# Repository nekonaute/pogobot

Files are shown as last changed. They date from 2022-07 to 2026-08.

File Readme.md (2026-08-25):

# Pogobot

## Overview 
The pogobot is a small robot designed for swarm robotics experiments, targeted at collective behaviour and social learning research.
The robot is composed of a head (above) with a iCE40UP5K FPGA chip including a softcore processor, an IMU, fast Infra-Red communication devices and a LED.
The head is plugged on a belly (under) which composed of even more LEDs, the motor controler, the battery and the battery regulation system.

## Git description
This project is divided into 5 folders :

- 3d-addons
- docs
- Hardware
- Software
- Scripts

3d-addons contains the 3d printable mesh necessary to assemble a complete robot. 

Hardware contains the schematics and other files to build your own robot from scratch. 

All the schematics were done using KiCad 6. You can find : 
- 'Belly' folder with the belly schematics
- 'Head' folder with the head schematics
- '3Dmodels' and other folders regroups all the libraries, 3D models and foorprints for KiCad.
   
Software contains the gateware / software / SDK builder in expert mode to upload inside the robot.
It exists 2 softwares inside the robot. 
- The bootloader is the one called when you boot the robot. It contains a gateware and the pogobios.
- The user space is called by a command inside the bootloader. It contains your code and a gateware. <br>
/!\ If you plan to use the pogobot in the user space please use the sdk [here](https://github.com/nekonaute/pogobot-sdk).
  
Scripts corresponds to the differents scripts used around the robot.

## Shortcuts to

- [Robot Assembly for Users](./docs/RobotAssembly.md)
- [Software documentation for Users](./docs/SoftwareUserGuide.md)
- [Software documentation for Experts](./Software/Readme.md)
- [Pogobot Remote Tool](./docs/IR-Remote.md)
- [Pogobot Charger Tool](./Hardware/Readme.md#charger)
- [Pogobot Wall Tool](./Hardware/Readme.md#ir-wall)
- [Pogobot Wall App](./Software/pogoWallApp/Readme.md)
- [Pogobject Tool](./Software/pogobject/Readme.md)
- [Hardware documentation](./Hardware/Readme.md)

# Pogobot Extended Universe

- [Pogobot Projet Entry Page](https://pogobot.github.io/)
- [SDK Repository](https://github.com/nekonaute/pogobot-sdk)
- [Pogobot2026 Tracking Software](https://github.com/keivan-amini/pogotrack)
- [Pogobot Simulator](https://github.com/Adacoma/pogosim)
- [Pogobot Software Addons](https://github.com/Adacoma/pogo-utils)

# Project History

To help the understanding, there is two version names used inside the project, one for the hardware and one for the software. <br> 
The following table gives an overview :

| hardware version | software version | comments |
|:---:|:---:|---|
| V3 | V1 | initial version |
| V3 | V2 | reduce communication speed to increase reliability |
| V3 | V2.1 | reduce header footprint |
| V3 | V2.2 | introduce short message and clean the pogobios |
| V3 | V2.2.1 | fix the IR programation problem |
| V3 | V2.3 | API standardization : motor |
| V3 | V2.4 | API standardization : IR messaging |

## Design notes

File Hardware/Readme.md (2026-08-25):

# Hardware
Here you can find the description and information for each part developped.

<!-- vscode-markdown-toc -->
- [Hardware](#hardware)
  - [Folder description](#folder-description)
  - [Pogobot robot](#pogobot-robot)
    - [Hardware schematic](#hardware-schematic)
    - [What's needed for 1 robot](#whats-needed-for-1-robot)
    - [Motor information](#motor-information)
    - [3d printed parts](#3d-printed-parts)
  - [USB UART progboard](#usb-uart-progboard)
  - [Charger](#charger)
  - [IR remote](#ir-remote)
  - [IR Wall](#ir-wall)
  - [Pogobject](#pogobject)

<!-- vscode-markdown-toc-config
	numbering=false
	autoSave=true
	/vscode-markdown-toc-config -->
<!-- /vscode-markdown-toc -->

## Folder description
In this folder, you can find 3d models and kicad files.

The folder :
- "3Dmodels" contains the 3D models for Kicad
- 'Belly" contains the kicad files for the belly
- "Charger" contains the kicad files for the charger
- "Footprints.pretty" is the Kicad library for custom footprints
- "Head" contains the kicad files for the head
- "pogo_object" contains the kicad files for the pogobject
- "remote" contains the kicad files for the board which host the head of a remote
- "remote_leds_strip" contains the kicad files for the "shower" part of a remote
- "remote_leds_wall_ctrl" contains the kicad files for the amplification signal for a led strip
- "remote_leds_wall_strip" contains the kicad files for the strip leds of a wall remote
- "Symbols" contains the custom symbols for kicad
- "usb-uart-progboard" contains the kicad files for the programmation board by cable

## Pogobot robot

### Hardware schematic
Here you can find the global view of the hardware.

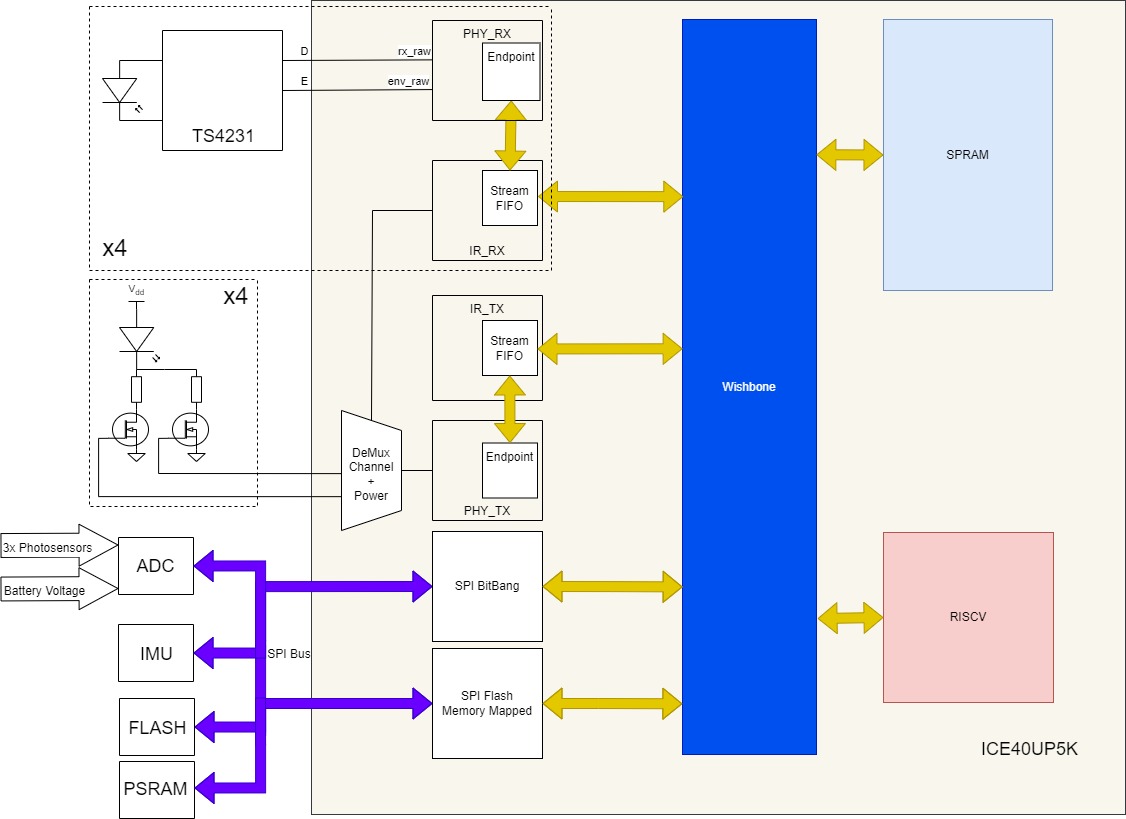
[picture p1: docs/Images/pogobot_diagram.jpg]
diagram


### What's needed for 1 robot

In order to complete a robot, you will need : 
- a belly and a head
- a 3v CR2 rechargeable Batery (Li-FePO4)
- 3 motors
- the different 3d printed parts

### Motor information
All the models are designed for the motors available here:
<!-- https://www.aliexpress.com/item/32918768766.html old ref -->
https://www.ebay.com/itm/115374108208

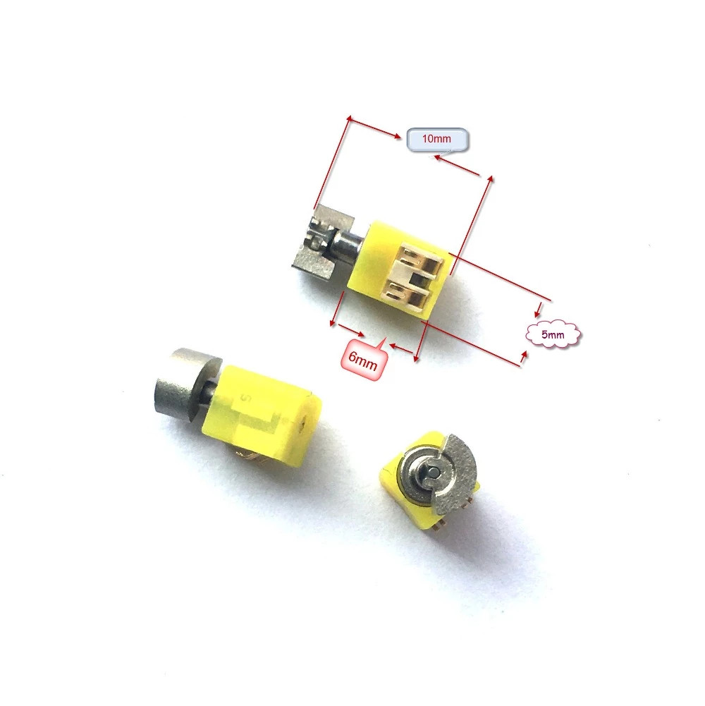
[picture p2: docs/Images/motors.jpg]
motor


### 3d printed parts
All the parts are available inside the folder '3d-addons', along with [assembly instructions](../3d-addons/Readme.md).

## USB UART progboard
In order to program the robot by cable, you need a USB to UART device connected between your computor and the FFC/FPC connector on the head. 
The folder 'Hardware/usb-uart-progboard' contains the Kicad files to produce a small board to program the robot. 
You also need :
- UMFT234XF board (https://www.mouser.fr/ProductDetail/FTDI/UMFT234XF?qs=NVftvxkm2thPJLzIkoAhbA%3D%3D)
- a FFC/FPC connector (8 pins, 0.5 mm, SMD/SMT, Right Angle, Dual Contact) like https://www.mouser.fr/ProductDetail/571-2328702-8
- a FFC/FPC cable (8 pins, 0.5 mm) like https://www.mouser.fr/ProductDetail/538-15166-0087
- a USB micro => USB cable

## Charger
There is two ways to recharge a pogobot:
- by the programming cable
- by the plus and minus pads on the head

In order to charge multiple robot at once, we develop a charger using pogopins that connect the plus and minus on the head of the robot by flipping the robot.

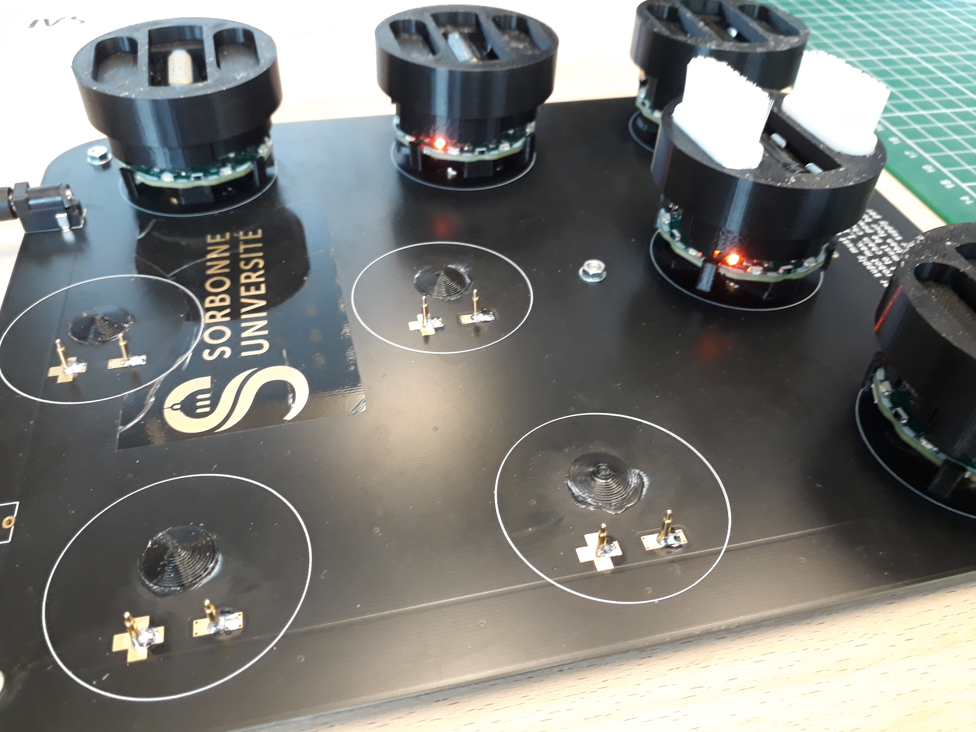
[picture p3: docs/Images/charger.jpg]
pogobot charger


The PCB cad files are available in the folder.
The pogopin used are these : https://www.digikey.fr/en/products/detail/preci-dip/90224-AS/5451911
We also used one power jack 5.1 embase connected to the power outlet. The second one is used, if you want to daisy chain multiple PCB (be careful, the total amps used).
:warning: The power plug has to expose the +5v on the inner contact and Ground on the outer contact. Please verify with a voltmeter before pluggin a robot.

We developed some small feet to mount with M3 screws on the PCB and some small cones in order to help the contacts for each robot.
Both 3d designs are available in the folder "3d-addons" (pogocharger*).

## IR remote
2 types of IR remote are possible. A small one and one with a shower. 

The small one is combination of a pogobot head + usb-uart-progboard + 3D structure (pogoremote_down.stl + pogoremote_up.stl) + 2 M3x10mm screws.

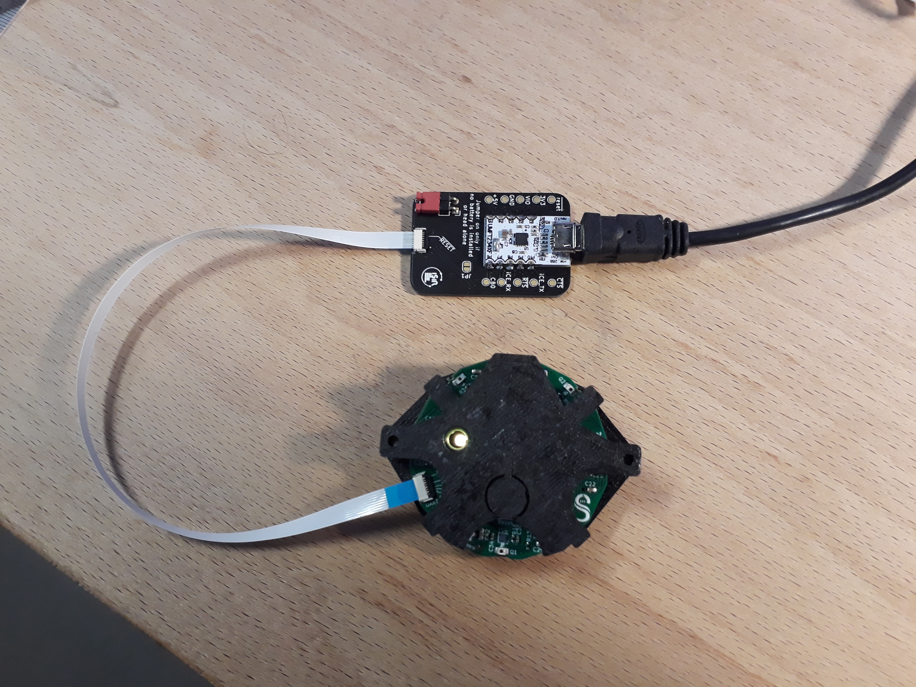
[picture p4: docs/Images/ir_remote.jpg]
IR_ Remote


The big one is combination of a pogobot head + remote + remote_Leds_strip + 3D structure

The leds are TSAL6200.

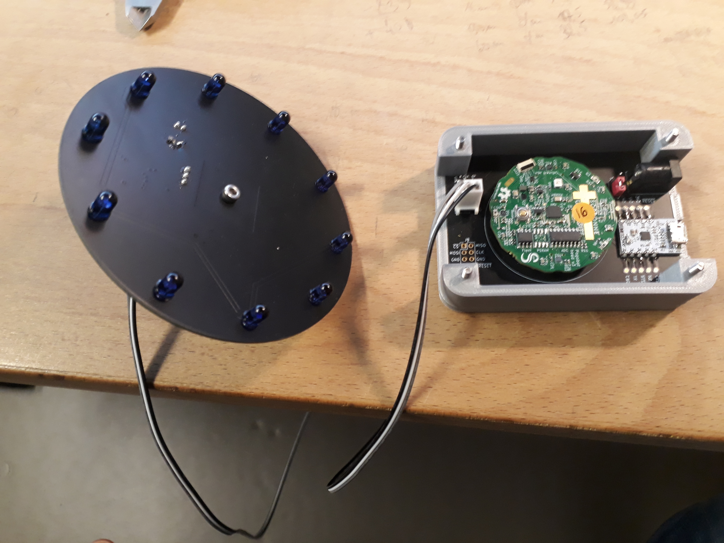
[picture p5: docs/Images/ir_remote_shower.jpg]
IR_ Remote


This version can use the USB alimentation or an external one (up to 12v) to extend the range of the remote. The jumper near the power jack determine the origin of the tension for the Leds.

## IR Wall 

The IR wall is a modified remote that can connect a long strip of Leds.
We didn't manage to find the correct Led strip for our application so we designed a strip led (remote_leds_wall_strip) that was produiced on flexible pcb. 

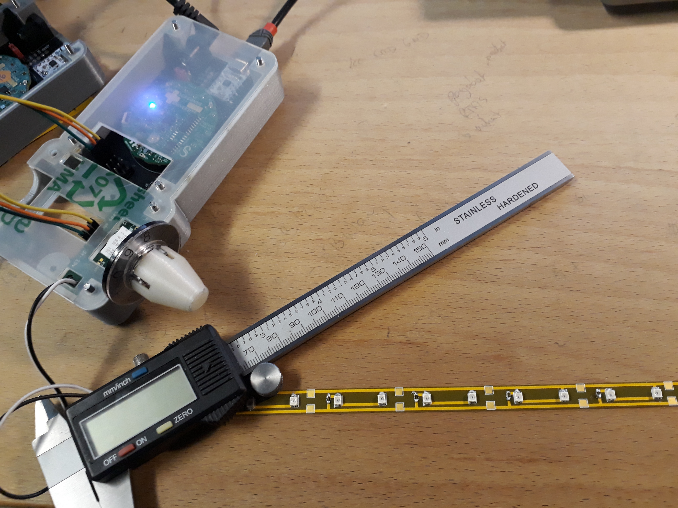
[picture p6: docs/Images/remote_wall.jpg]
IR_ Remote


To produice a IR wall, you need a pogobot head + remote + remote_leds_wall_ctrl + remote_leds_wall_strip. 

The leds are VSM3940x01.

## Pogobject

The pogobject is composed of a dfrobot firebeatle + pogobot head + pogo_object PCB. Through WIFI, it can be possible to send command to the pogobot head and so to change the message send by the object.

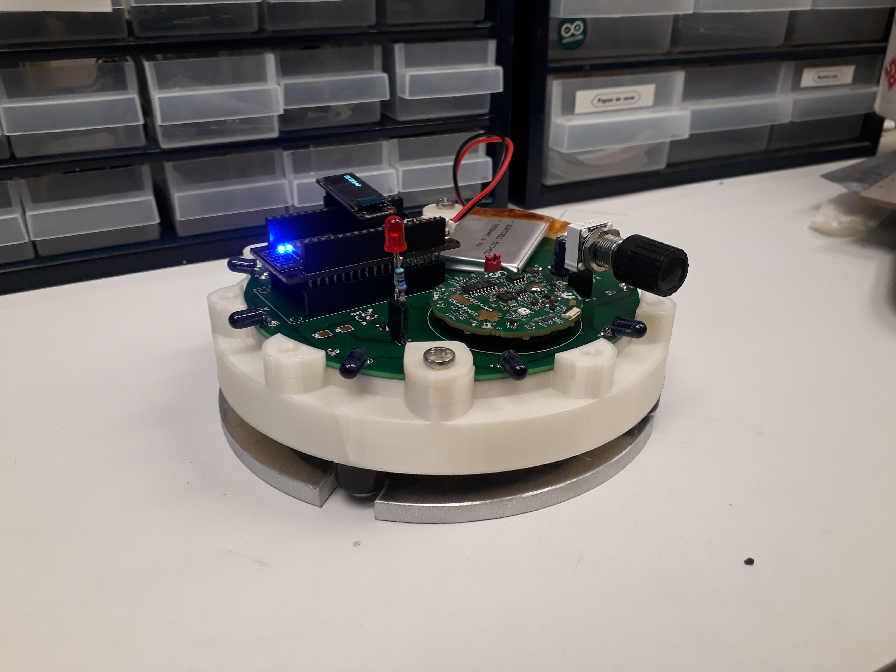
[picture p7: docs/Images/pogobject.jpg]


The pogobject is a large PCB that contains all the electronics. It is placed inside a 3d printed structure. This structure is placed on 4 caster with metal ball (pololu item 953) in order to be pushed by the robot. To make it fixed a aluminum weight is used to held it in place. 

The leds are TSAL6200.

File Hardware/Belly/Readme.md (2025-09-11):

# Belly
Belly board (Kicad project) to use with head board (pogobot v2).
Holds the battery, battery charger, motors, ...

## Belly v2
file : bellyv2

## Belly V3
file : pogobot_belly

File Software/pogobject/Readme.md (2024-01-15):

# Pogobject
The Pogobject is an object that can interact with pogobots using Infrared (IR) communication.
It features:
- IR message sending capability
- REST API control
- LEDs output control
- Battery-powered capability
- A screen

It is composed of a custom PCB, a Pogobot v3 head, and a DFRobot FireBeetle ESP8266.

## Pogobject configuration
In order to configure the SSID and the password of your WIFI, move the pogobject in configuration mode by connecting D9 to VCC and restart the pogobject.

A new WIFI "PogobjectConfig" should appear with the password "pogobotconfig".
Connect to the WIFI and go to the adress http://192.168.4.1 , enter the information.
Reconnect D9 to GND and restart the pogobject. 

You should now be connected to your network.

## Pogobject Directory
This directory contains the code for the FireBeetle to be used with the Arduino IDE.
Instructions and library versions are available within the code.

Tested with the arduino IDE 1.8.13 and 2.2.1
this code is the fusion of example from the libraries
- aREST (https://github.com/marcoschwartz/aREST v2.9.7)
- SoftwareSerial
- dfRobot u8g2 (https://github.com/olikraus/u8g2 v2.27.2 or v2.34.22)
- board library FireBeetle-ESP8266 (https://raw.githubusercontent.com/DFRobot/FireBeetle-ESP8266/master/package_firebeetle8266_index.json or http://download.dfrobot.top/boards/package_DFRobot_index.json v2.3.3)

## Pogobject Web Control Directory
This directory contains a web app that can interact more easily with the Pogobject.
Both the Pogobject and the web app need to be on the same wifi network in order to work.
Instructions are provided on the web page.

## Pogobject API

The following API is available on the pogobject.

- Allows to access to the pogobject status. <br> 
http://X.X.X.X/

- Allows to send a cmd to the pogobot though the UART prompt. <br> 
http://X.X.X.X/cmd?params=YYY  <br> 
YYY -> all bios cmd compabible with the pogobot (without "", spaces are understand).<br> 
Example: http://X.X.X.X/cmd?params=autotest led
 
- Allows to change the PWM ratio of the pin "LED_PIN". <br> 
http://X.X.X.X/led?params=Y <br> 
Y -> [0:1024] <br>
Example: http://X.X.X.X/led?params=256
 
- Alows to reboot the pogobot for whatever is needed. <br>
http://X.X.X.X/reboot_p 

- update the battery reading. <br> 
http://X.X.X.X/read_bat

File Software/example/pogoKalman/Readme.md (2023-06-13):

# [Projet P-ANDROIDE - M1/S2 - 2023 - Partie calibration et filtre de Kalman](http://androide.lip6.fr/?q=node/674)

## Pogobot Calibration 

Functions used to calibrate the Pogobot: find the correct motor values (between 0 and 1023) which make the robot move forward without turning. Keep in mind that Pogobots are very sensitive to environmental perturbations. Dust, an uneven ground and older toothbrushes can affect the trajectory of a robot.<br />
To calibrate the robot, we turn on the motor for a short time, check if the robot turned left or right, ajust the values of the motors accordingly and repeat a few times.

**Functions:**

```C
void pogobot_quick_calibrate(int power, int* leftMotorVal, int* rightMotorVal);
```
>Call this function to calibrate the motors of the Pogobot at roughly ***power***. The value of ***power*** has to be between 0 and 1023. However, the lower the value, the less precise the calibration will be. Keeping ***power*** between 524 and 716 is a good idea.<br />
>The values are returned as integers through ***leftMotorVal*** and ***rightMotorVal***.

```C
void pogobot_calibrate(int power, int startup_duration, int try_duration, int number_of_tries, float correction, int* leftMotorVal, int* rightMotorVal);
```
>Same function as before, but gives more control to the user over its parameters.<br />
>Call this function to calibrate the motors of the Pogobot at roughly ***power***. During each try, the motors are turned on for ***startup_duration***ms before we actually collect IMU data. Then IMU data is collected during ***try_duration***ms. The experience is repeated ***number_of_tries*** times. Each time, robot_rotation****correction*** is applied to one of the motors. <br />
>In ***pogo_quick_calibrate()***, ***startup_duration*** = 500 ; ***try_duration*** = 750 ; ***number_of_tries*** = 15 and ***correction*** = 50.0f.<br />
>Be careful, if your pogobot is mounted backward, you might need to assign a negative value to ***correction***. 

## Kalman filter implementation in C

The Kalman filter is executable at runtime. It is used to reduce the noise from the IMU. In particular, the z axis of the gyroscope (horizontal rotation) can be used to determine if the pogobot is turning. It is used in pogobot_calibrate() but can be used elsewhere.

**Functions:**

```C
void extendedKalmanFilter(
    float z_k_observation_vector[][C],        // [1][6] 6x1
    float state_estimate_k_minus_1[][C],      // [1][6] 6x1
    float P_k_minus_1[][C],                   // [6][6] 6x6
    float A_k_minus_1[][C],                   // [6][6] 6x6
    float process_noise_v_k_minus_1[][C],     // [1][6] 6x1
    float Q_k[][C],                           // [6][6] 6x6
    float R_k[][C],                           // [6][6] 6x6
    float H_k[][C],                           // [6][6] 6x6
    float sensor_noise_w_k[][C],              // [1][6] 6x1
    // returns:
    float state_estimate_k[][C],              // [1][6] 6x1
    float P_k[][C]                            // [6][6] 6x6
    );
```
>Function to filter out noisy data (makes a prediction from the previous iteration then correct it with the new data). z_k_observation_vector should be the data read by the IMU : {acc[0], acc[1], acc[2], gyro[0], gyro[1], gyro[2]}. <br />
>The results are stored in state_estimate_k and P_k. At the next iteration, you should assign their values to P_k_minus_1 and state_estimate_k_minus_1. The other parameters don't need to be changed (initialize once then forget about them).

```C
void initExtendedKalmanFilter(
    int power,
    float state_estimate_k_minus_1[][C],      // [1][6] 6x1
    float P_k_minus_1[][C],                   // [6][6] 6x6
    float A_k_minus_1[][C],                   // [6][6] 6x6
    float process_noise_v_k_minus_1[][C],     // [1][6] 6x1
    float Q_k[][C],                           // [6][6] 6x6
    float R_k[][C],                           // [6][6] 6x6
    float H_k[][C],                           // [6][6] 6x6
    float sensor_noise_w_k[][C]               // [1][6] 6x1
    );
```
>Declare arrays and pass them as arguments of this function to initialize them, after which you can pass them as the corresponding parameters of extendedKalmanFilter().

## Debug, display and convenient functions

Useful functions, linked to the calibration of the pogobots or with a more general purpose.

**Functions:**

```C
void print_float(float i, int precision);
```
>Print a float to the console, because printf("%f", myFloat); doesn't work on pogobots. They're too cool for that.<br />
>Example: printf("one point two = "); print_float(1.22f, 10); printf("\n"); <br />
>Result: "one point two = 1.2\n"

```C
void print_kalman(int i, float state_estimate_k[][6], float acc[], float gyro[3]);
```
>Print to the console the IMU values with and without the Kalman filter. The parameter ***i*** is the current time in milliseconds.

```C
void pogobot_motor_jump_set(int power, int motor);
```
>Safely initiate motor value (short jumpstart if ***value*** is under 512).

```C
void combine_arrays(float res[], float arr1[], float arr2[], int len1, int len2);
```
>Combine arr1[len1] and arr2[len2] into res[len1+len2] (res = arr1 + arr2 in python)

```C
void split_array(float base[], float arr1[], float arr2[], int len1, int len2);
```
>Split base[len1+len2] into arr1[len1] and arr2[len2] by putting the len1 first elements into arr1 and len1+1 to len1+len2 into arr2

```C
void set_all_leds(int r, int g, int b);
```
>Set all of the pogobot's leds to the same color.

```C
void anim_same(void);
```
>Pretty animation.

```C
void anim_blink(int r, int g, int b, int number_of_blinks);
```
>All leds blinks ***number_of_blinks*** times. 

```C
void print_f_list(float* list, int len, int precision);
```
>Print an array of floats to the console with \t in between each element. There is no \n.

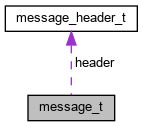
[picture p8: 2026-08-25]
Software/docs/doxygen/html/structmessage__t__coll__graph.png

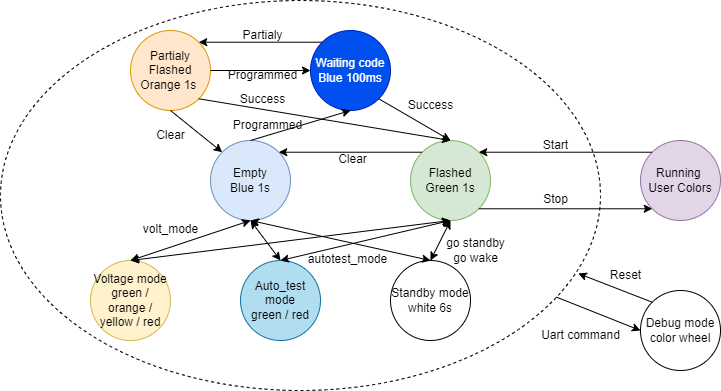
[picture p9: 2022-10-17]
docs/Images/pogobot_led_status.png

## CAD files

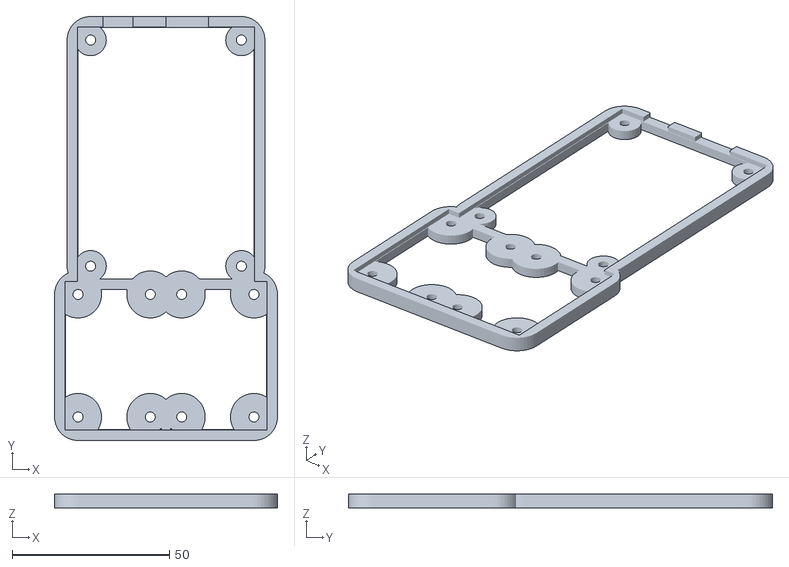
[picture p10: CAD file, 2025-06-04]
3d-addons/Misc/pogowall_ctrl_down.stl
71.0 x 135.0 x 4.60

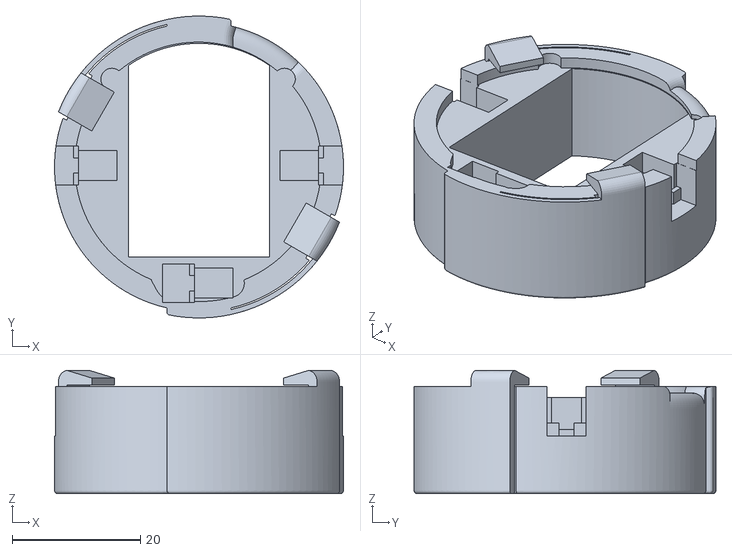
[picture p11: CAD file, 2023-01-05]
3d-addons/Pogobot2023/pogobot_bellyv3_cap.stl
45.0 x 47.0 x 19.2

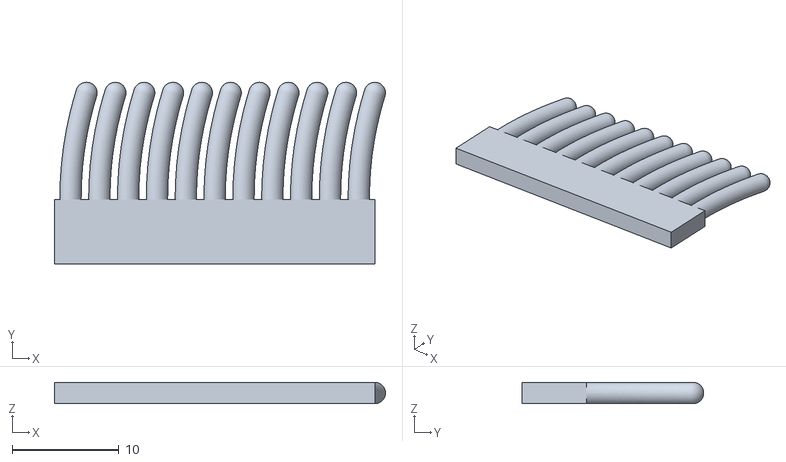
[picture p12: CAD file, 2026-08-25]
3d-addons/Pogobot2026/brushes.stl
31.0 x 17.0 x 2.00

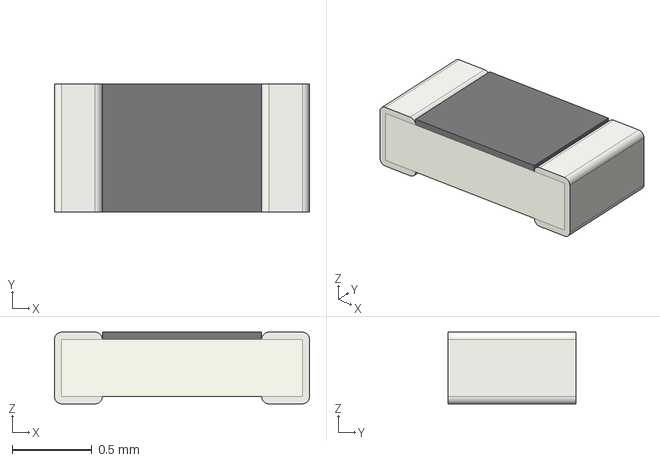
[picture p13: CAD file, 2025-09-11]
Hardware/3Dmodels/R_0603_1608Metric.step
1.60 x 0.8 x 0.45 mm

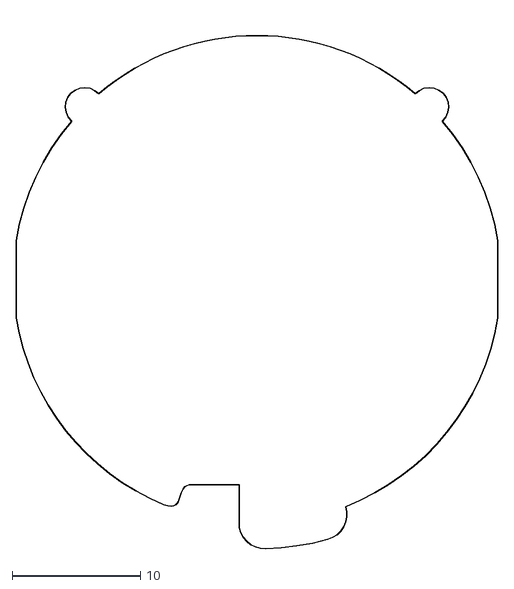
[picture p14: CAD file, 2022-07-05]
Hardware/Belly/untitled.dxf
37.5 x 41.5

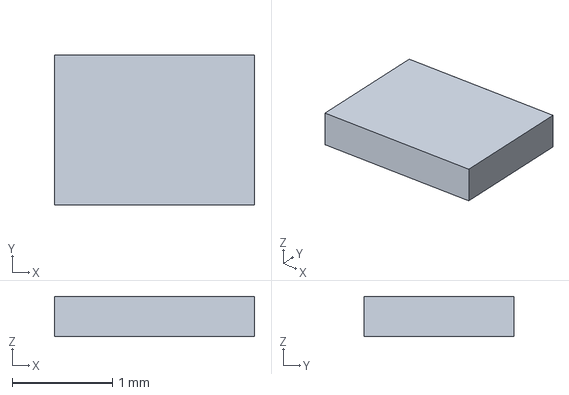
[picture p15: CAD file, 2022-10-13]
Hardware/remote_leds_wall_strip_12v/3Dmodels/TLA2024.step
2.00 x 1.50 x 0.4 mm

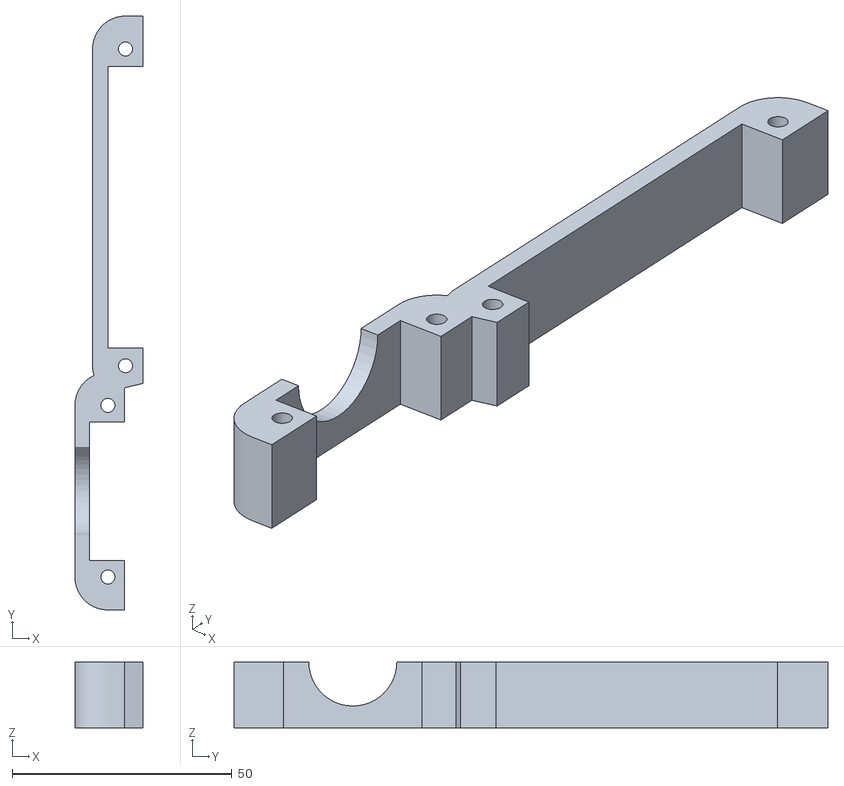
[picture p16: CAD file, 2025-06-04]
3d-addons/Misc/pogowall_ctrl_up_r.stl
15.5 x 135.0 x 15.0

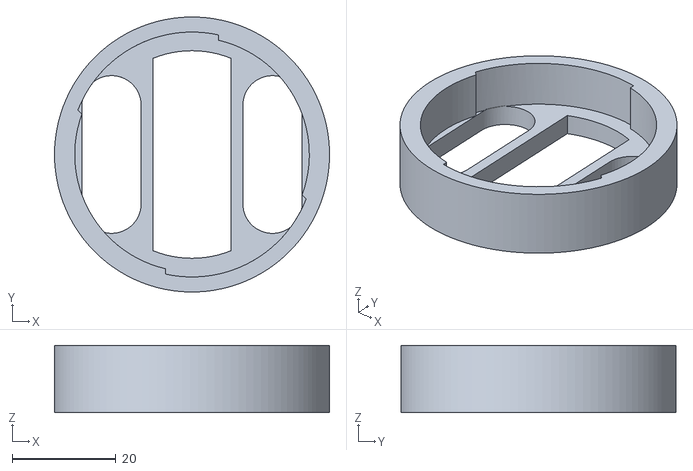
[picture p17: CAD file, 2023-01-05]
3d-addons/Pogobot2023/pogobot_bellyv3_skirt_brosse.stl
53.0 x 53.0 x 13.0

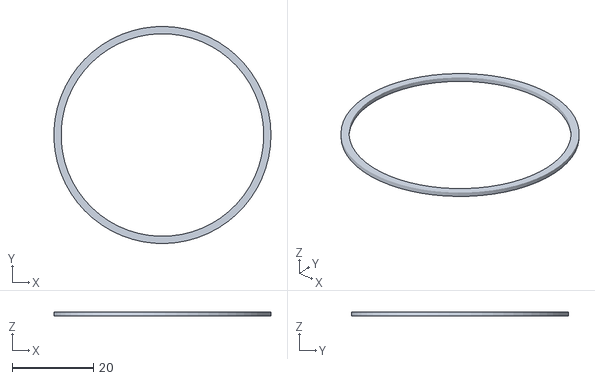
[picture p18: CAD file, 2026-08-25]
3d-addons/Pogobot2026/black_anulus.stl
53.4 x 53.4 x 1.00

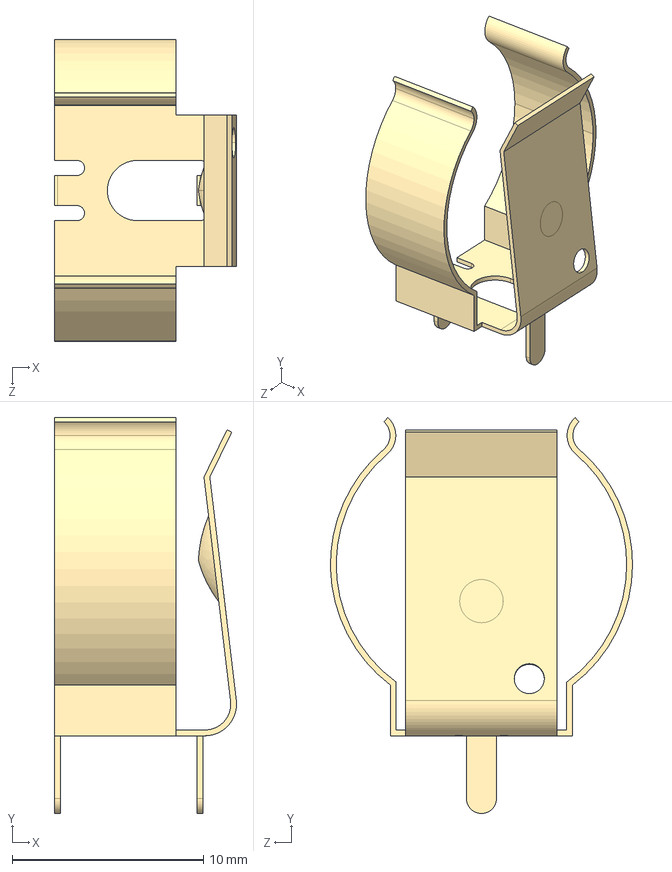
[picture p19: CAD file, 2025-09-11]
Hardware/3Dmodels/battery_clip.step
9.52 x 20.7 x 15.8 mm

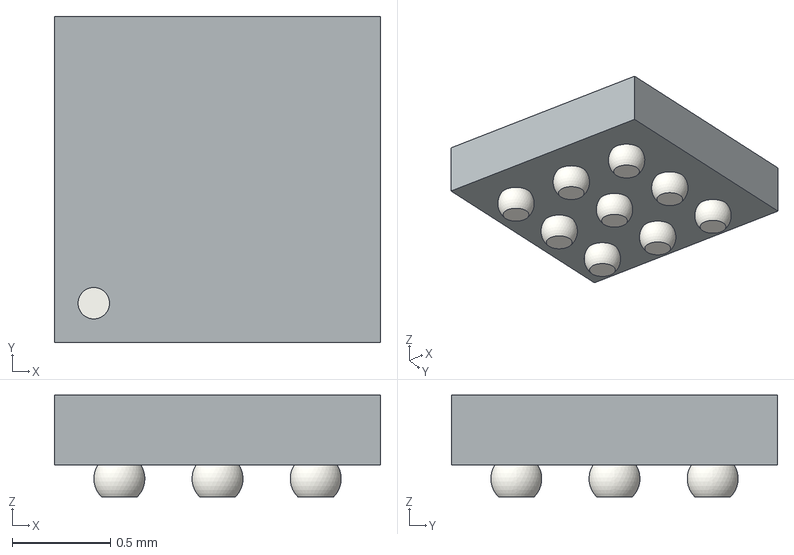
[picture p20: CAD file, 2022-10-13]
Hardware/remote_leds_wall_strip_12v/3Dmodels/TS4231.step
1.66 x 1.66 x 0.517 mm

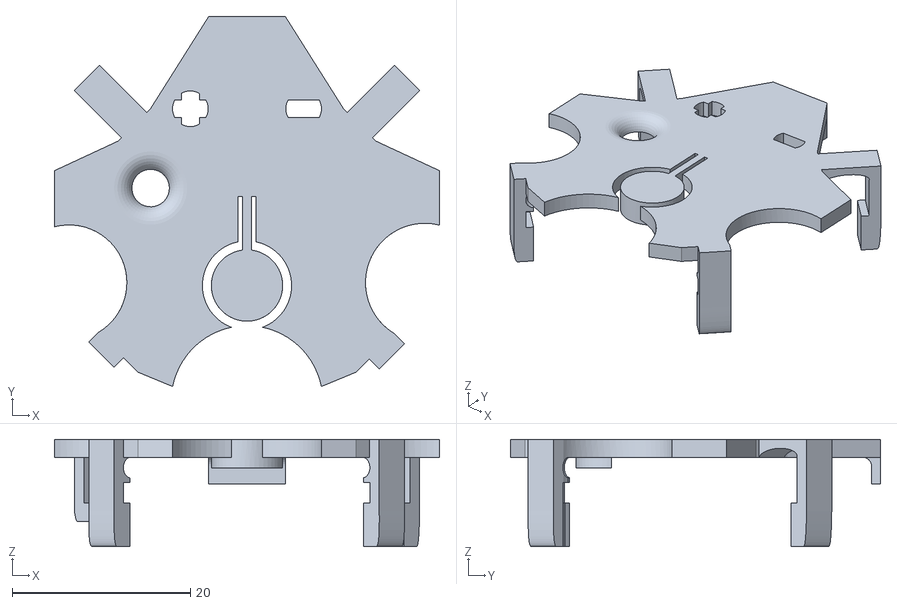
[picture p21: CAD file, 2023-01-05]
3d-addons/Pogobot2023/pogobot_headv3_hat.stl
43.2 x 41.5 x 12.0

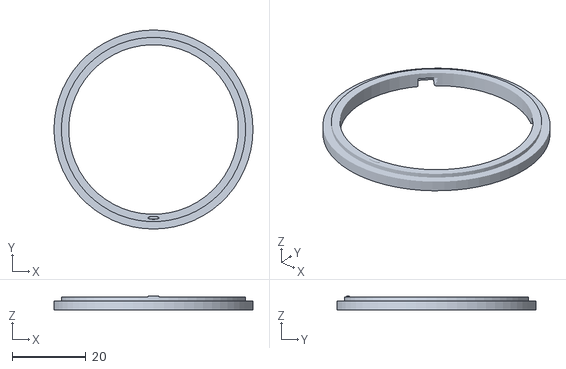
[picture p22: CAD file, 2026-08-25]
3d-addons/Pogobot2026/white_anulus.stl
53.9 x 53.9 x 3.84

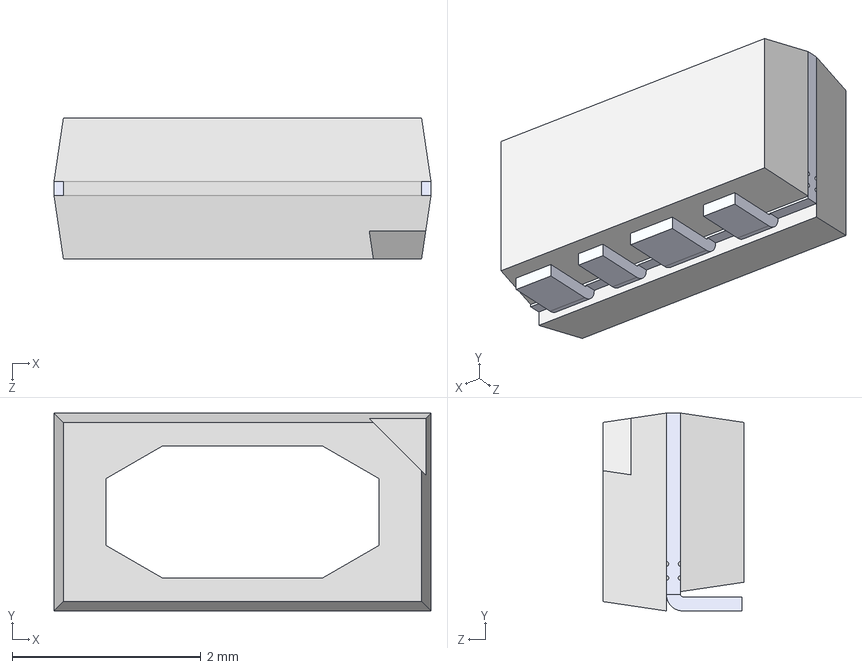
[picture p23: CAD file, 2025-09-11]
Hardware/3Dmodels/IN-PI42TASPRPGPB.step
4.00 x 2.10 x 1.50 mm

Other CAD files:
3d-addons/Misc/pogowall_ctrl_up_l.stl
Hardware/remote_leds_wall_strip_12v/3Dmodels/VEMD10940.step
3d-addons/Misc/pogoremote_up.stl
3d-addons/Pogobot2023/pogobot_bellyv3_skirt.stl
3d-addons/Misc/pogocharger_cone.stl
3d-addons/Misc/pogocharger_feet.stl
3d-addons/Misc/pogoremote_down.stl
3d-addons/Pogobot2026/black_capsule.stl
3d-addons/Pogobot2026/hat.stl
3d-addons/Pogobot2026/red_filters_back.stl
3d-addons/Pogobot2026/red_filters_front.stl
3d-addons/Pogobot2026/white_arrow.stl
Hardware/3Dmodels/10132797-015100LF.stp
Hardware/3Dmodels/10132797-035100LF.stp
Hardware/3Dmodels/C_0603_1608Metric.step
Hardware/3Dmodels/LED_0603_1608Metric.step
Hardware/3Dmodels/MCP73123-22SI_MF.stp
Hardware/3Dmodels/MSK12C02.stp
Hardware/3Dmodels/R_0805_2012Metric.step
Hardware/3Dmodels/WSON-8-1EP_2x2mm_P0.5mm_EP0.9x1.6mm.step
Hardware/remote_leds_wall_strip_12v/3Dmodels/2199119-3.stp
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

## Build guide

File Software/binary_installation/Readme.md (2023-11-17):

# How to use the compiled binaries

## Using the ice40 dev board

If you have access to the ice40 dev board and the complementary pogobot board as in the Readme section " Upload an empty or faulty robot ",
you can use the script "program_remote.sh" or "program_robot.sh" available for the version you need.

## Using Litex_term.py
### Installing the gateware and the pogobios

From the folder "pogobot/Software":

```
cp binary_installation/example_images.json .
```

Modify the path depending on the version needed and execute (replace XXX to match your configuration):

```
./litex_term.py --serial-boot --images example_images.json --safe /dev/ttyUSBXXX
```

Reboot the robot. It will then display the "pogoboot >" prompt

For the robot to download and restart with the new code, execute (on the robot):

```
serialboot
```

### Installing the remote gateware and pogobios

It is the same as the previous section but it uses the "example_images_remote.json" file instead.

/!\ The gateware of the remote and of a robot are different so the code of a robot can't run on a remote.

### In the case of the bootloader

In the folder "pogobot/Software" (replace XXX to match your configuration):

```
./litex_term.py --serial-boot --kernel=binary_installation/install_APIv2.2.1/bootloader/bootloader_pogobotv3/bootloader.bin --kernel-adr=0x200000 --safe /dev/ttyUSBXXX
```

On the robot, execute:

```
serialboot
```

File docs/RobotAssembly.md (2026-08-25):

# Robot Assembly
## Pogobot 2026

_not yet written_

## Pogobot 2023

### Printing info
The different models have been printed in PLA with an Ultimaker2+ with a layer height of 0.2mm without support or brim.

To assemble a robot, you need to print a skirt, a capsule and a hat for the version of your belly. <br>
After printed the capsule, you have to set free the tabs by gently cut under.

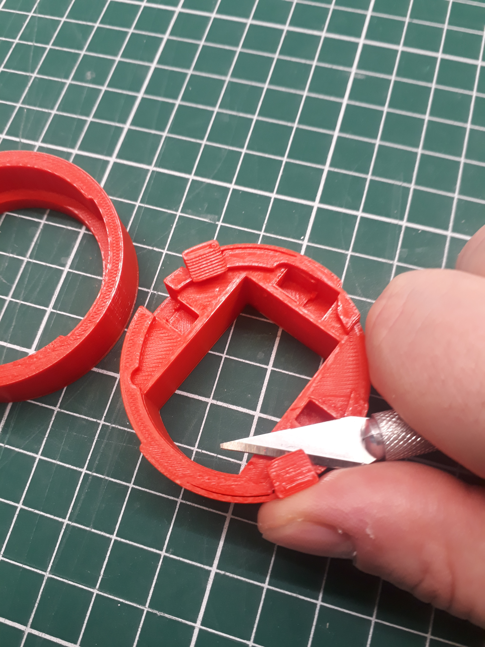
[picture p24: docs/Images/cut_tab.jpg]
cut_tab


HINT: The hat has to be returned to be printed without support.

### 3D parts Assembly
- First, place the motors inside the 3 holes.
- Then, place the robot inside the capsule.
- Finally, place the robot+capsule inside the skirt.

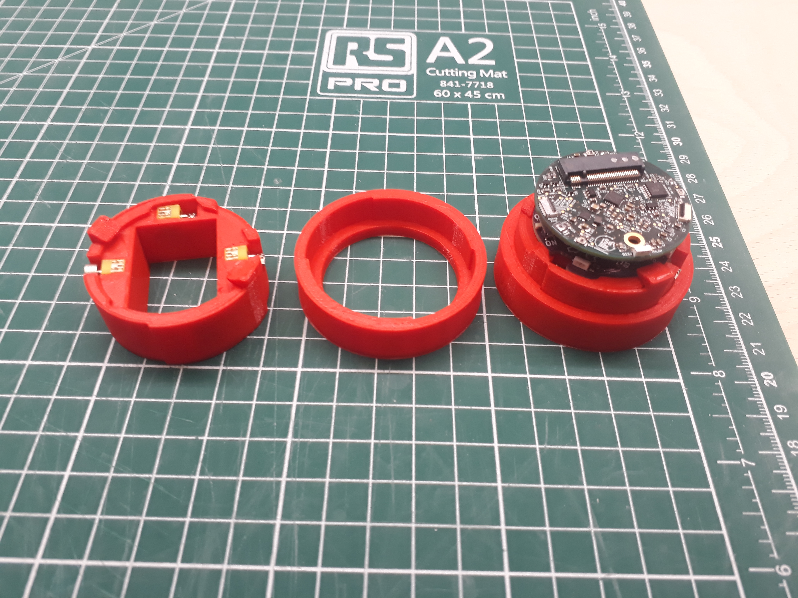
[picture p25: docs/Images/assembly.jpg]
assembly


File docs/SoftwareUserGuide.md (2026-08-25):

# Software Guide for Users

A practical introduction to programming a Pogobot for the first time. This document has been generated using human written parts and assembled with ChatGPT.

---

# 1. Introduction and Setup

## How are pogobot programmed ?

A Pogobot has programs written in **C** and uploaded either:

* through a **USB cable** (single robot),
* or through a **remote infrared uploader** (“shower” / walls) for multiple robots.

Typical Pogobot programs:

* blink LEDs,
* move motors,
* communicate through infrared messages,
* react to sensors,
* coordinate with other robots.

---

## Installing the Environment

You need the Pogobot SDK and toolchain installed before compiling programs. See [SDK repository and installation instructions](https://github.com/nekonaute/pogobot-sdk/tree/main#pogobot). As a reference point once the SDK is installed, you can navigate to the `helloworld` example under `pogobot-sdk/examples/helloworld`.

---

## Typical Program Structure

A Pogobot project usually contains:

```text
my_program/
├── main.c
└── Makefile
```

With the Makefile being essentially the same in every program, and as such can be copied from examples. Most programs follow this structure:

```c
#include "pogobot.h"

int main(void)
{
    pogobot_init();

    while (1)
    {
        // read sensors

        // communicate

        // move

        // blink LEDs

        msleep(10);
    }
}
```

---

# 2. First Program and Core SDK Concepts

## Minimal Example

### main.c

```c
#include "pogobot.h"

int main(void)
{
    pogobot_init();

    printf("init ok\n");

    while (1)
    {
        // Blue LED
        pogobot_led_setColor(0, 0, 255);

        // Move left motor
        pogobot_motor_set(motorL, motorFull);
        pogobot_motor_set(motorR, motorStop);

        msleep(500);

        printf("HELLO WORLD !!!\n");

        // Red LED
        pogobot_led_setColor(255, 0, 0);

        // Move right motor
        pogobot_motor_set(motorL, motorStop);
        pogobot_motor_set(motorR, motorFull);

        msleep(500);
    }
}
```

This program:

* initializes the robot,
* alternates LED colors,
* alternates motor movement,
* prints text to the serial terminal.

---

## Initialization

Every program must start with:

```c
pogobot_init();
```

Without initialization, most hardware features will not work.

---

## LEDs

Set the head LED color:

```c
pogobot_led_setColor(r, g, b);
```

Each value ranges from:

```text
0 → 255
```

Example:

```c
pogobot_led_setColor(255, 0, 0);
```

Red LED.

---

## Timing

Most programs use:

```c
msleep(milliseconds);
```

Example:

```c
msleep(500);
```

Waits 500 ms.

---

## Motors

Pogobot has 3 vibration motors:

```text
motorR
motorL
motorB
```

Motor power levels:

```text
motorStop          = 0
motorQuarter       = 256
motorHalf          ≈ 512
motorThreeQuarter  ≈ 716
motorFull          = 1023
```

Example:

```c
pogobot_motor_power_set(motorL, motorFull);
pogobot_motor_power_set(motorR, motorStop);
```

---

## Debug Printing

Use standard C printing:

```c
printf("Hello\n");
```

Messages appear in the serial terminal and are extremely useful for debugging.

---

## Sensors

### Ambient Light Sensors

```c
int value = pogobot_photosensors_read(0);
```

Sensors:

```text
0 = back
1 = front-left
2 = front-right
```

---

### Battery Voltage

```c
int mv = pogobot_battery_voltage_read();
```

Returns millivolts.

---

### IMU

```c
float acc[3];
float gyro[3];

pogobot_imu_read(acc, gyro);
```

Axes:

```text
0 = X
1 = Y
2 = Z
```

---

## Timers

### Stopwatch Example

```c
time_reference_t timer;

pogobot_stopwatch_reset(&timer);

// some computation

int32_t elapsed =
    pogobot_stopwatch_get_elapsed_microseconds(&timer);

printf("%ld\n", elapsed);
```

---

### Periodic Timer Example

```c
time_reference_t timer;

pogobot_timer_init(&timer, 1000000);

while (1)
{
    if (pogobot_timer_has_expired(&timer))
    {
        printf("1 second elapsed\n");

        pogobot_timer_offset_origin_microseconds(
            &timer,
            1000000
        );
    }
}
```

---

# 3. Infrared Communication and Swarm Programming

Pogobots communicate using infrared.

Typical workflow:

1. send a message,
2. periodically update IR system,
3. check if messages arrived,
4. read messages.

---

## Sending a Message

```c
char msg[] = "hello";

pogobot_infrared_sendShortMessage_omni(
    (uint8_t*)msg,
    sizeof(msg)
);
```

This broadcasts in all directions.

---

## Receiving Messages

```c
pogobot_infrared_update();

if (pogobot_infrared_message_available())
{
    message_t msg;

    pogobot_infrared_recover_next_message(&msg);

    printf("Message received\n");
}
```

---

## Example: Distributed Genetic Algorithm

The following program demonstrates:

* infrared swarm communication,
* distributed decision-making,
* mutation and selection,
* LEDs,
* motors,
* random genome generation.

Each robot:

1. generates a random binary genome,
2. computes a fitness score,
3. broadcasts its genome,
4. copies stronger genomes from neighbors,
5. occasionally mutates,
6. gradually converges toward an optimal genome.

This example comes from the distributed genetic algorithm demo in the SDK, `examples/demo_d2_9BIS`.

### Key Ideas

Genome representation:

```c
typedef struct my_data_t
{
    uint16_t genome;
    uint16_t fitness;
} my_data_t;
```

Broadcasting data:

```c
pogobot_infrared_sendLongMessage_omniGen(
    (uint8_t *)( &my_data ),
    sizeof( my_data )
);
```

Receiving and comparing genomes:

```c
if ( recept->fitness > my_data.fitness )
{
    my_data.genome = recept->genome;
}
```

Mutation:

```c
my_data->genome ^= 1UL << n;
```

This type of program is useful for experimenting with:

* swarm intelligence,
* collective optimization,
* decentralized coordination,
* emergent behavior.

---

# 4. Compiling, Uploading, and Running Programs

## Compiling

Inside your project folder:

```bash
make
```

If compilation succeeds, you should obtain:

```text
build/firmware.bin
build/firmware.elf
```

---

## Hardware Setup

For USB programming:

1. connect the robot to the programming board using the ribbon cable,
2. connect the programming board to your computer with USB.

When correctly powered, LEDs usually blink several colors during startup.

---

## Uploading Through USB

Connect to the robot:

```bash
make connect TTY=/dev/ttyUSB0
```

Replace:

```text
/dev/ttyUSB0
```

with the correct serial device on your machine.

---

## Terminal Workflow

After running `make connect`:

1. press ENTER,
2. wait for the prompt,
3. use terminal commands directly.

Upload firmware:

```text
serialboot
```

Run the uploaded program:

```text
run
```

Exit terminal:

```text
Ctrl+C Ctrl+C
```

---

## Uploading to Multiple Robots (Infrared Remote)

Connect the remote uploader:

```bash
make connect TTY=/dev/ttyUSB0
```

Then:

1. press ENTER,
2. type:

```text
run
```

3. power on robots,
4. erase firmware:

```text
rc_erase
```

5. flash robots:

```text
rc_flash_robot
```

6. start all robots:

```text
rc_start
```

Robots typically turn green when upload succeeds.

---

## Important Warning

Never use:

```text
serialboot
```

when connected to the infrared remote uploader.

Doing so overwrites the remote firmware itself.

---

# 5. Workflow, Troubleshooting, and Safety

## Recommended Development Workflow

A common workflow is:

1. modify `main.c`,
2. compile:

```bash
make
```

3. connect:

```bash
make connect
```

4. upload:

```text
serialboot
```

5. run:

```text
run
```

6. observe LEDs, movement, and debug prints,
7. repeat.

---

## Troubleshooting

### Robot Does Not Respond

Try:

* unplug/replug USB,
* restart terminal,
* power cycle robot,
* verify serial device path.

---

### Infrared Stops Working

Firmware 2.6 has a known IR bug.

Avoid resetting robots while they receive IR messages.

If IR breaks:

1. move robot away from others,
2. reset several times,
3. power cycle,
4. reflash firmware if needed.

---

### Program Too Large

Firmware 2.6 may fail when:

* `.data` exceeds about 41960 bytes,
* and the robot is started through `rc_start`.

Check size with:

```bash
riscv64-unknown-elf-size --format=SysV build/bin/firmware.elf
```

---

## Updating Robot Firmware

Firmware update instructions:

[Firmware update instructions](https://github.com/nekonaute/pogobot/blob/main/Software/Readme.md#upload-a-empty-or-faulty-robot)

Typical commands:

```bash
./program_robot.sh
```

or

```bash
./program_remote.sh
```

depending on the device.

---

## Safety Rules

* Power down robots before charging.
* Never leave robots charging unattended overnight.
* Do not leave robots on the arena after experiments.
* Fully charging takes about 2 hours.
* Avoid resetting robots during IR communication.

---

## Recommended Next Steps

After completing your first program:

1. explore the `examples/` folder,

2. experiment with:

   * swarm communication,
   * obstacle avoidance,
   * synchronization,
   * light-following behaviors,

3. create reusable helper functions,

4. test multi-robot behaviors with the infrared uploader.

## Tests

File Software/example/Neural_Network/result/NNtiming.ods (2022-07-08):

Pour 100 itérations
 | nb_inputs | nb_outputs | nb_hidden_layers | nb_hidden_nodes_per_layer | dimension | time x100 (s) | time (s) | Fréquence 1 itération
 | 20 | 10 | 3 | 30 | 2700 | 17,5 | 0,175 | 5,71428571428571
 | 20 | 10 | 4 | 30 | 3600 | 23,1 | 0,231 | 4,32900432900433
 | 40 | 20 | 6 | 40 | 10400 | 52 | 0,52 | 1,92307692307692
 | 10 | 5 | 3 | 15 | 675 | 6,3 | 0,063 | 15,8730158730159
 | 40 | 20 | 6 | 60 | 21600 | 84,7 | 0,847 | 1,18063754427391
 | 40 | 10 | 3 | 40 | 5200 | 27,2 | 0,272 | 3,67647058823529
 | 4 | 2 | 1 | 5 | 30 | 0,552 | 0,00552 | 181,159420289855
 | 4 | 2 | 2 | 5 | 55 | 0,952 | 0,00952 | 105,042016806723
 | 4 | 2 | 3 | 5 | 80 | 1,245 | 0,01245 | 80,3212851405622
 | 4 | 2 | 4 | 5 | 105 | 1,865 | 0,01865 | 53,6193029490617
 | 4 | 2 | 5 | 5 | 130 | 2,311 | 0,02311 | 43,271311120727
 | 4 | 2 | 6 | 5 | 155 | 2,78 | 0,0278 | 35,9712230215827
 | 4 | 2 | 7 | 5 | 180 | 3,214 | 0,03214 | 31,1138767890479
 | 4 | 2 | 8 | 5 | 205 | 3,642 | 0,03642 | 27,4574409665019
 | 4 | 2 | 9 | 5 | 230 | 4,201 | 0,04201 | 23,8038562247084
 | 4 | 2 | 10 | 5 | 255 | 4,545 | 0,04545 | 22,002200220022
 | 8 | 4 | 1 | 9 | 108 | 1,32 | 0,0132 | 75,7575757575758
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

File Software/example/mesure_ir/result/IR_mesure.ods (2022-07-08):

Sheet: monodirection
mesure pogobot
Angle 0°
vitesse Ko/s | size octet |  |  |  | 1ko => xus
distance cm | 32 | 64 | 128 | 256 |  | 32 | 64 | 128 | 256
0 | 8,47457627118644 | 15,3139356814701 | 25,6410256410256 | 38,6100386100386 | 0 | 118000 | 65300 | 39000 | 25900
0,5 | 8,47457627118644 | 15,3139356814701 | 25,6410256410256 | 38,6100386100386 | 0,5 | 118000 | 65300 | 39000 | 25900
1 | 8,47457627118644 | 15,3139356814701 | 25,6410256410256 | 38,6100386100386 | 1 | 118000 | 65300 | 39000 | 25900
1,5 | 8,47457627118644 | 15,3139356814701 | 25 | 38,6100386100386 | 1,5 | 118000 | 65300 | 40000 | 25900
2 | 5,20833333333333 | 8,62068965517241 | 8,08407437348424 | 6,12745098039216 | 2 | 192000 | 116000 | 123700 | 163200
2,5 | 0,302388872089507 | 0,666666666666667 | 1,39275766016713 |  | 2,5 | 3307000 | 1500000 | 718000
3 |  |  |  |  | 3
Angle +15°
vitesse Ko/s | size octet |  |  |  | 1ko => xus
distance cm | 32 | 64 | 128 | 256 |  | 32 | 64 | 128 | 256
0 | 8,47457627118644 | 15,3139356814701 | 25 | 38,6100386100386 | 0 | 118000 | 65300 | 40000 | 25900
0,5 | 8,47457627118644 | 15,3139356814701 | 25 | 38,6100386100386 | 0,5 | 118000 | 65300 | 40000 | 25900
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

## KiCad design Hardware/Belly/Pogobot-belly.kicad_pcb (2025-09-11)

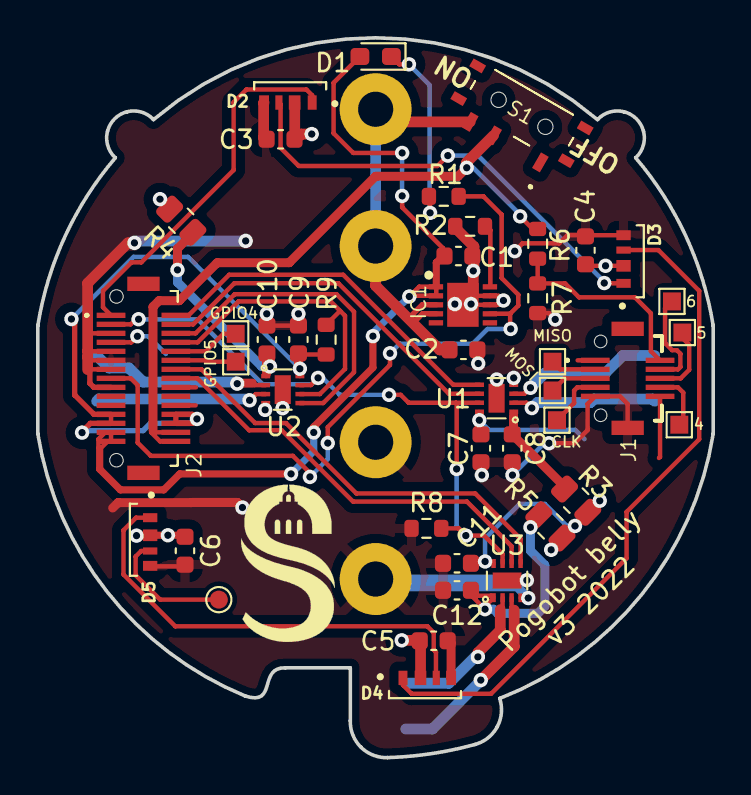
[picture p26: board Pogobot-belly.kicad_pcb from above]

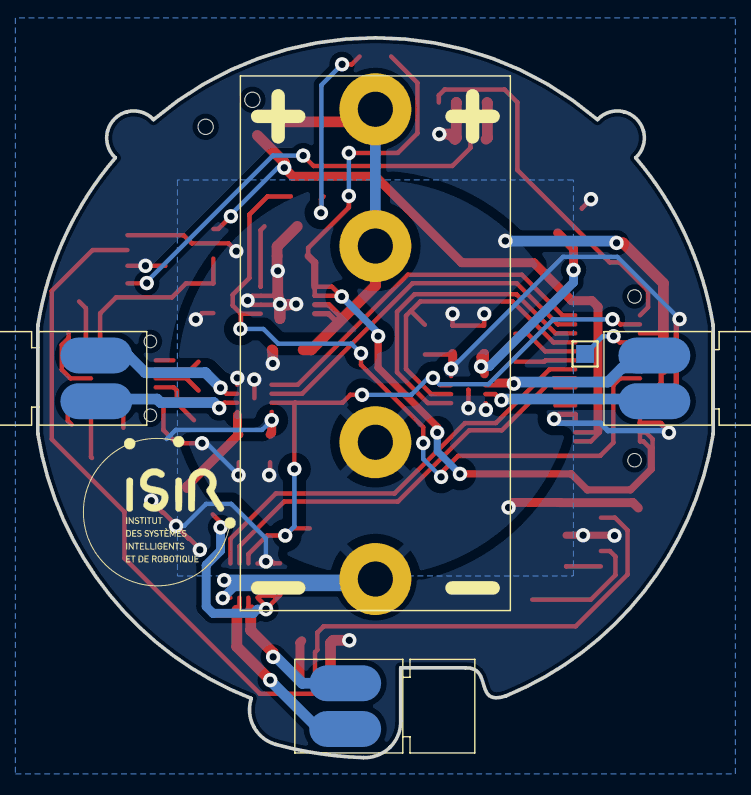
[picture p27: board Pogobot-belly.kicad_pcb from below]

Board: 2 copper layers, 37.5 x 40.0 mm, 47 parts (5 on the bottom side), 39 nets.

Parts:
4, 5, 6: TestPoint; TestPoint_Pad_1.0x1.0mm
C1, C2: 4.7uF; C_0603_1608Metric
C3, C4, C5, C6: 1uF; C_0603_1608Metric
C7, C8, C9, C10, C11, C12: 100n; C_0603_1608Metric
CLK: TestPoint; TestPoint_Pad_1.0x1.0mm
D1: LED; LED_0603_1608Metric_Pad1.05x0.95mm_HandSolder
D2, D3, D4, D5: IN-PI42TASPRPGPB; LED_IN-PI42TASPRPGPB
GPIO4, GPIO5: TestPoint; TestPoint_Pad_1.0x1.0mm
IC1: MCP73123-22SI_MF; SON50P300X300X100-11N-D
J1: 10132797-015100LF; 10132797015100LF
J2: 10132797-035100LF; 10132797035100LF
J3: CR2 Battery Holder; CR2_Holder
M1, M2, M3: Motor_DC; Vibrating_5x6mm_DC_motor
MISO: TestPoint; TestPoint_Pad_1.0x1.0mm
MOSI: TestPoint; TestPoint_Pad_1.0x1.0mm
R1: 1K; R_0603_1608Metric
R2, R6, R7, R8, R9: 10K; R_0603_1608Metric
R3, R4, R5: 0; R_0805_2012Metric
S1: MSK12C02
TP1: TestPoint; TestPoint_Pad_1.0x1.0mm
TP4: RGB_Out; TestPoint_Pad_D1.0mm
U1, U2, U3: DRV8837C; WSON-8-1EP_2x2mm_P0.5mm_EP0.9x1.6mm

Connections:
+3V3: C3.1, C4.1, C5.1, C6.1, C7.1, C9.1, C11.1, D2.2 (VDD), D3.2 (VDD), D4.2 (VDD), D5.2 (VDD), J2.12, J2.13, J2.18, J2.19, R3.1, R4.1, R5.1, R9.1, U1.8 (VCC), U2.8 (VCC), U3.8 (VCC)
+5V: C1.1, D1.2 (A), IC1.1 (VDD_1), IC1.2 (VDD_2), J2.14, J2.15
+BATT: J2.16, J2.17, R6.1, S1.B1 (COM)
/CH4: 4.1, J1.7
/CH5: 5.1, J1.8
/CH6: 6.1, J1.9
/CH7: J1.10, R6.2, R7.1
/prog: IC1.10 (PROG), R2.2
CDONE: J2.4, TP1.1
GND: C1.2, C2.2, C3.2, C4.2, C5.2, C6.2, C7.2, C8.2, C9.2, C10.2, C11.2, C12.2, D2.4 (GND), D3.4 (GND), D4.4 (GND), D5.4 (GND), IC1.8 (VSS_1), IC1.9 (VSS_2), IC1.11 (EP), J1.5, J1.MP2, J2.3, J2.5, J2.6, J2.7, J2.9, J3.2, R2.1, R7.2, R8.2, U1.4 (GND), U1.9 (GND), U2.4 (GND), U2.9 (GND), U3.4 (GND), U3.9 (GND)
GPIO0: J2.30, U1.5 (IN2)
GPIO1: J2.29, U1.6 (IN1)
GPIO2: J2.28, U2.5 (IN2)
GPIO3: J2.27, R9.2, U2.6 (IN1)
GPIO4: GPIO4.1, J2.26
GPIO5: GPIO5.1, J2.25
GPIO6: J2.24, U3.5 (IN2)
GPIO7: J2.23, U3.6 (IN1)
GPIO8: J2.2, R8.1, U1.7 (~SLEEP), U2.7 (~SLEEP), U3.7 (~SLEEP)
LED_CHARGE: IC1.7 (STAT), J2.8, R1.2
unnamed: C2.1, IC1.3 (VBAT_1), IC1.4 (VBAT_2), J3.1, S1.C1 (NO)
unnamed: C8.1, R3.2, U1.1 (VM)
unnamed: C10.1, R4.2, U2.1 (VM)
unnamed: C12.1, R5.2, U3.1 (VM)
unnamed: D1.1 (K), R1.1
unnamed: D2.3 (DOUT), D3.1 (DIN)
unnamed: D3.3 (DOUT), D4.1 (DIN)
unnamed: D4.3 (DOUT), D5.1 (DIN)
unnamed: D5.3 (DOUT), TP4.1
unnamed: M1.1 (+), U1.2 (OUT1)
unnamed: M1.2 (-), U1.3 (OUT2)
unnamed: M2.1 (+), U2.2 (OUT1)
unnamed: M2.2 (-), U2.3 (OUT2)
unnamed: M3.1 (+), U3.2 (OUT1)
unnamed: M3.2 (-), U3.3 (OUT2)
RGB_LED_OUT: D2.1 (DIN), J2.1
SPI_CLK: CLK.1, J1.4
SPI_MISO: J1.2, MISO.1
SPI_MOSI: J1.3, MOSI.1

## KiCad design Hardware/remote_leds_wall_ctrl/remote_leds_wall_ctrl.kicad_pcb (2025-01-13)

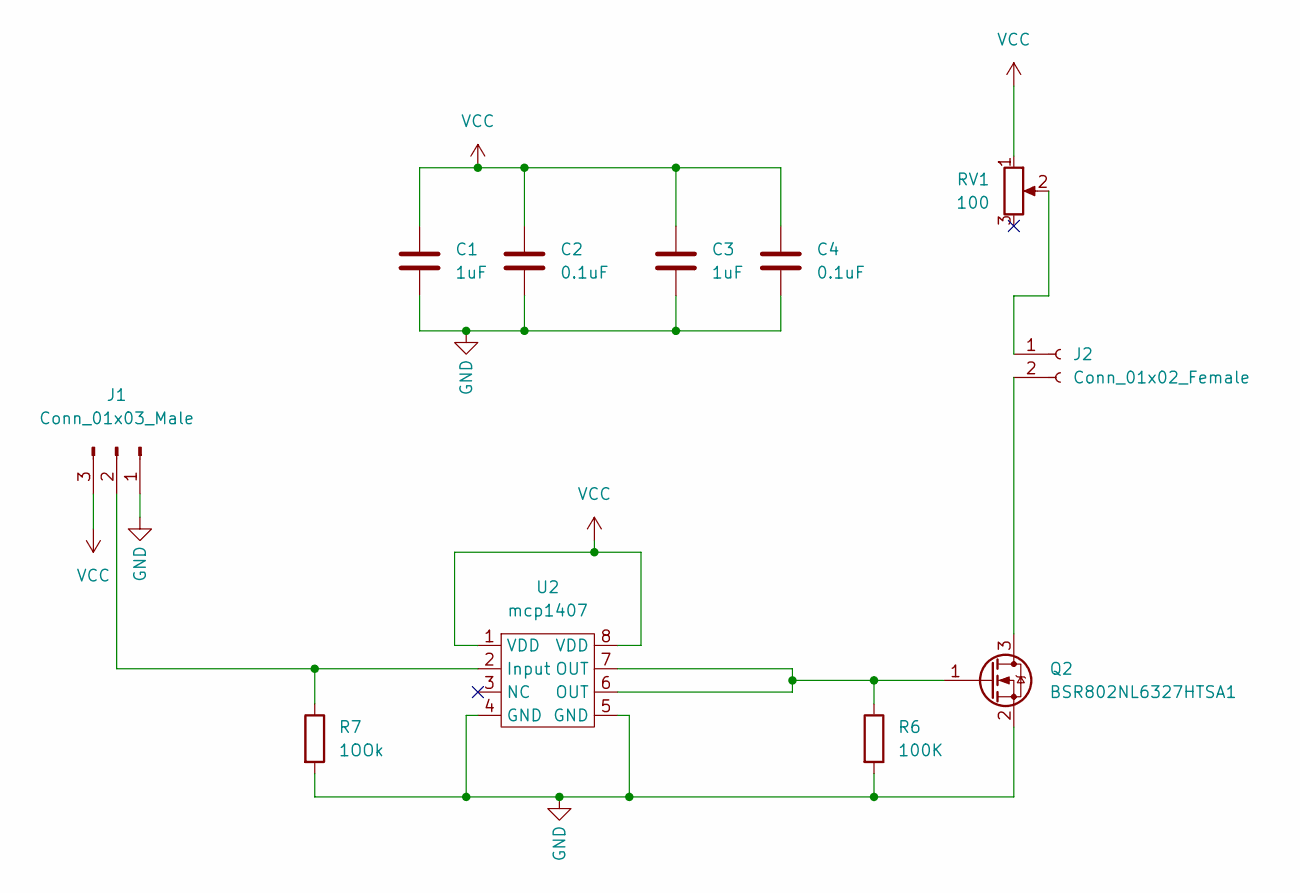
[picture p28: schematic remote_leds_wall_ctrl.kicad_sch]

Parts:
C1: 1uF; C_0805_2012Metric_Pad1.18x1.45mm_HandSolder
C2: 0.1uF; C_0805_2012Metric_Pad1.18x1.45mm_HandSolder
C3: 1uF; CP_Radial_D5.0mm_P2.00mm
C4: 0.1uF; CP_Radial_D5.0mm_P2.00mm
J1: Conn_01x03_Male; PinHeader_1x03_P2.54mm_Vertical
J2: Conn_01x02_Female; PinHeader_1x02_P2.54mm_Vertical
Q2: BSR802NL6327HTSA1; SOT-23
R6: 100K; R_0805_2012Metric_Pad1.20x1.40mm_HandSolder
R7: 1OOk; R_0805_2012Metric_Pad1.20x1.40mm_HandSolder
RV1: 100; PinHeader_1x03_P2.54mm_Vertical
U2: mcp1407; SOIC-8_3.9x4.9mm_P1.27mm

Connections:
GND: C1.2, C2.2, C3.2, C4.2, J1.1, Q2.2 (S), R6.2, R7.2, U2.4 (GND), U2.5 (GND)
unnamed: J1.2, R7.1, U2.2 (Input)
unnamed: J2.1, RV1.2
unnamed: J2.2, Q2.3 (D)
unnamed: Q2.1 (G), R6.1, U2.6 (OUT), U2.7 (OUT)
VCC: C1.1, C2.1, C3.1, C4.1, J1.3, RV1.1, U2.1 (VDD), U2.8 (VDD)

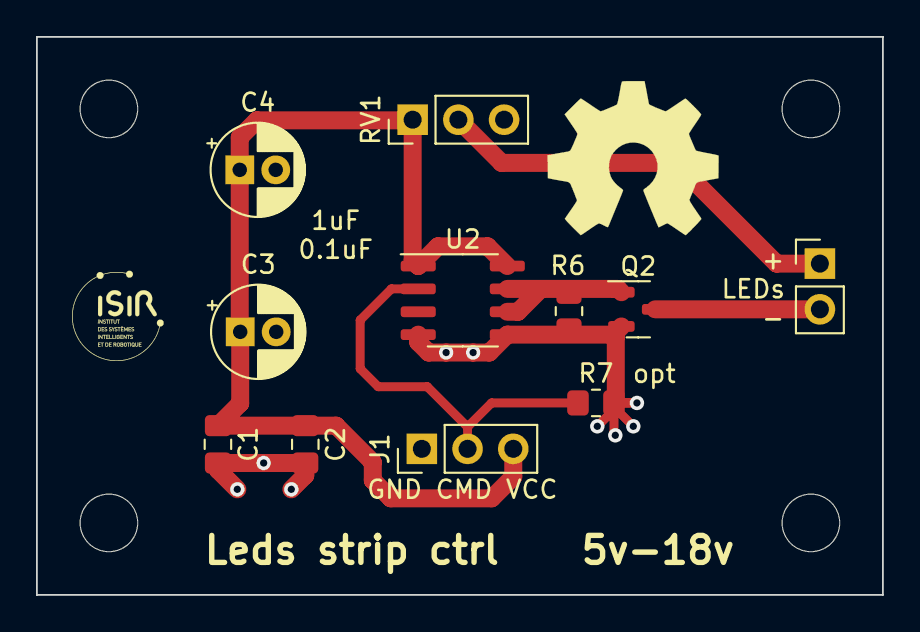
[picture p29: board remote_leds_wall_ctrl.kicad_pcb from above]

Board: 2 copper layers, 47.0 x 31.0 mm, 11 parts (0 on the bottom side), 6 nets.

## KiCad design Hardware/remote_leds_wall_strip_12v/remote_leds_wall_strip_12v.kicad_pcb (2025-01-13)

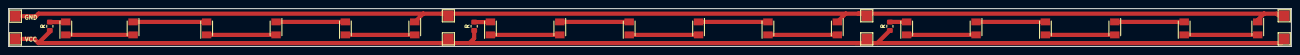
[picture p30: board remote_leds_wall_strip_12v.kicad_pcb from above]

Board: 2 copper layers, 305.1 x 9.0 mm, 29 parts (0 on the bottom side), 20 nets.

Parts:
L1, L2, L3, L4, L5, L6, L7, L8, L9, L10, L11, L12, L13, L14, L15, L16, L17, L18: VSMB3940X01-GS08; LEDM3528X185N
R: 15; R_0805_2012Metric_Pad1.20x1.40mm_HandSolder
R#2, R#3: 15; R_0805_2012Metric_Pad1.20x1.40mm_HandSolder
TP1, TP2, TP3, TP4, TP5, TP6, TP12, TP27: TestPoint; TestPoint_Pad_2.5x2.5mm

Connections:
GND: L4.1 (K), L10.1 (K), L16.1 (K), TP1.1, TP3.1, TP6.1, TP12.1
unnamed: L1.1 (K), L2.2 (A)
unnamed: L1.2 (A), L18.1 (K)
unnamed: L2.1 (K), L3.2 (A)
unnamed: L3.1 (K), L4.2 (A)
unnamed: L5.1 (K), L6.2 (A)
unnamed: L5.2 (A), R#3.2
unnamed: L6.1 (K), L7.2 (A)
unnamed: L7.1 (K), L8.2 (A)
unnamed: L8.1 (K), L9.2 (A)
unnamed: L9.1 (K), L10.2 (A)
unnamed: L11.1 (K), L12.2 (A)
unnamed: L11.2 (A), R.2
unnamed: L12.1 (K), L13.2 (A)
unnamed: L13.1 (K), L14.2 (A)
unnamed: L14.1 (K), L15.2 (A)
unnamed: L15.1 (K), L16.2 (A)
unnamed: L17.1 (K), L18.2 (A)
unnamed: L17.2 (A), R#2.2
VCC: R.1, R#2.1, R#3.1, TP2.1, TP4.1, TP5.1, TP27.1

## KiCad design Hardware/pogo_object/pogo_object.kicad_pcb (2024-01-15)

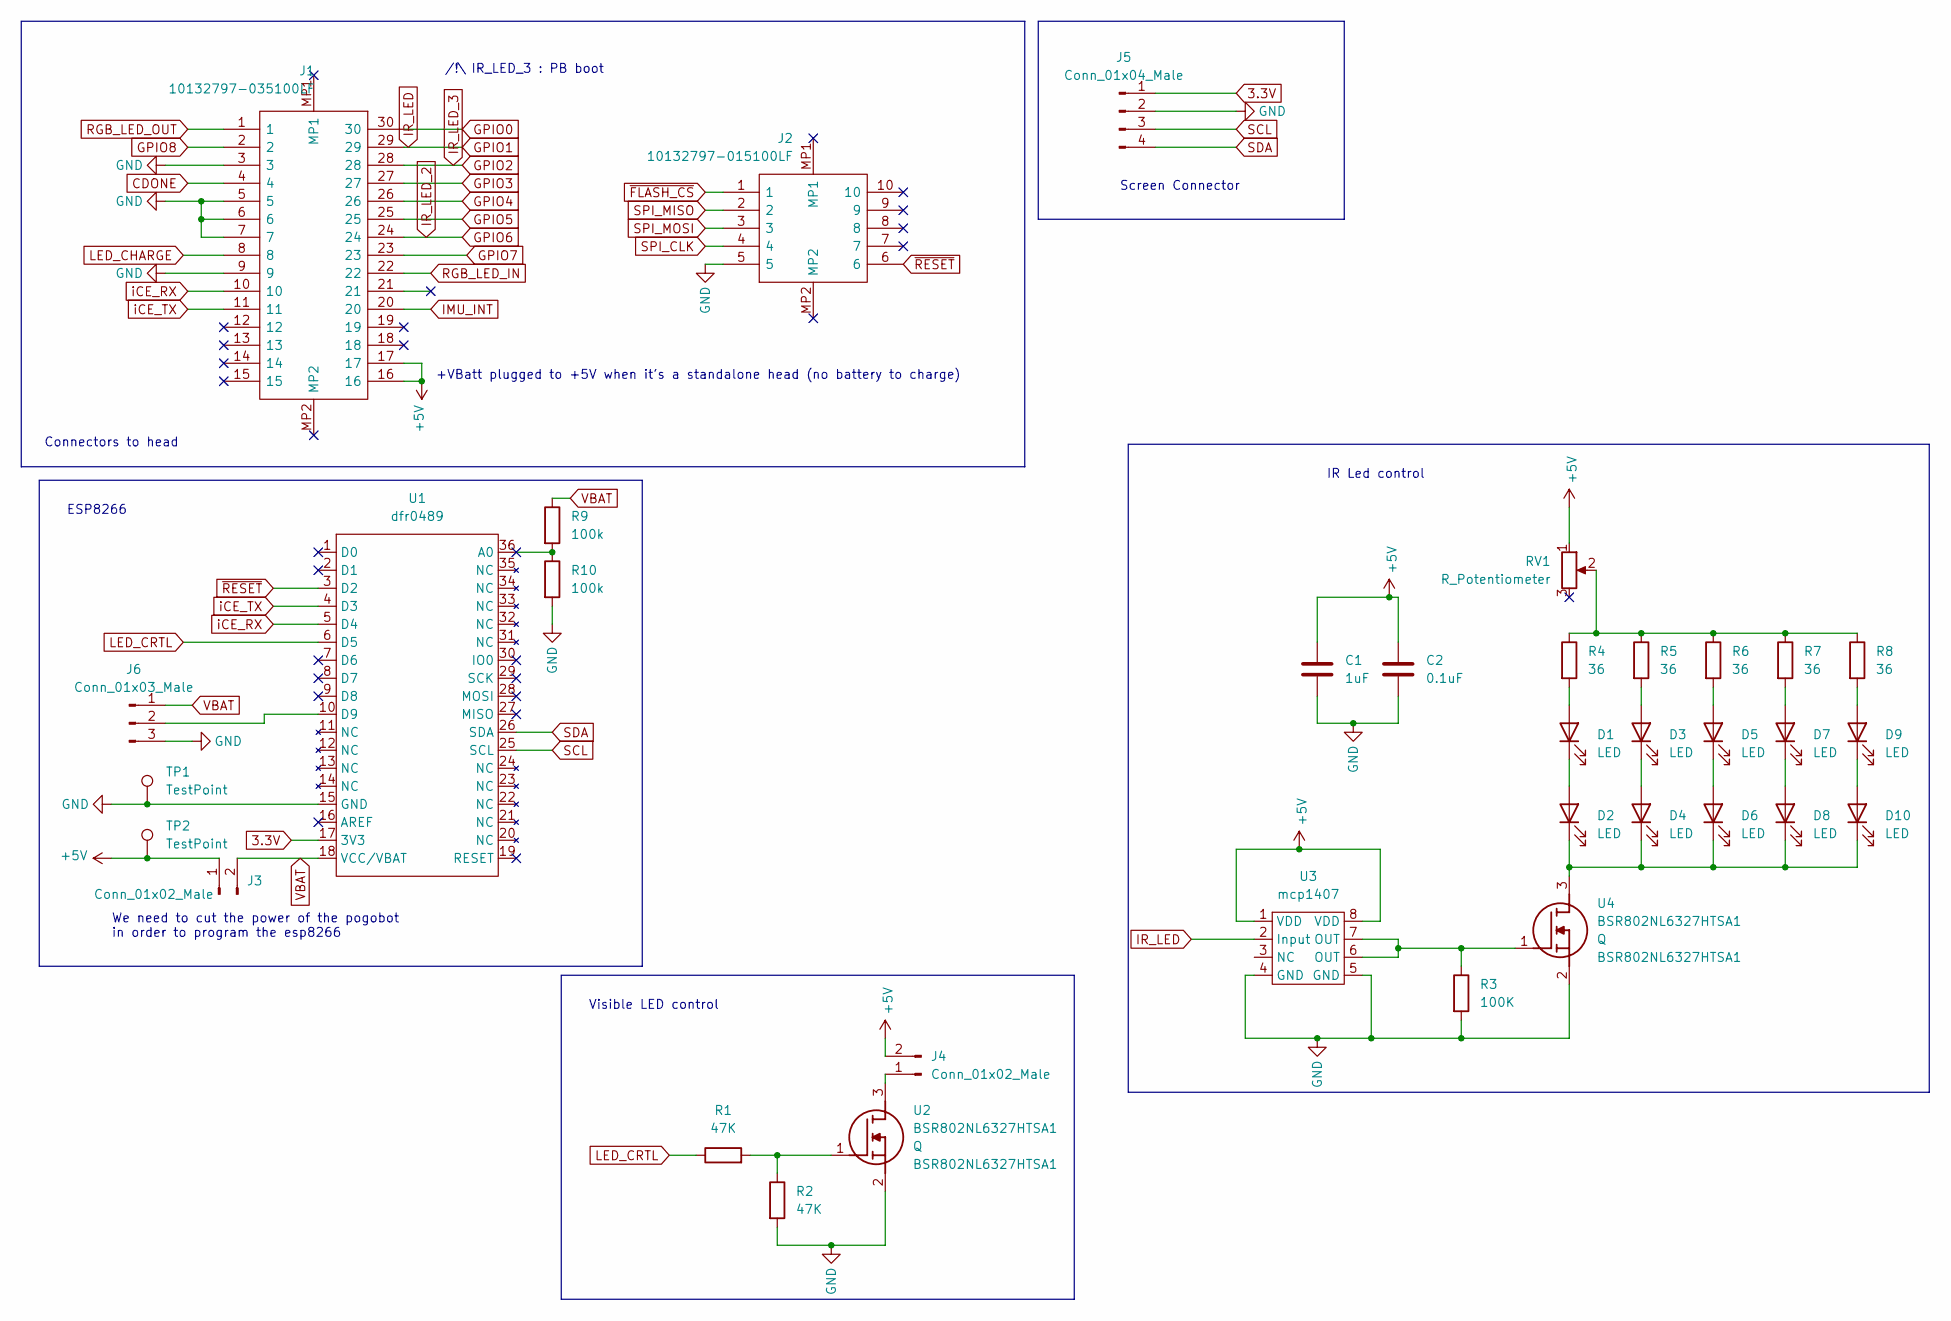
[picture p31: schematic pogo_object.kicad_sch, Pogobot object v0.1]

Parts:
C1: 1uF; CP_Radial_D8.0mm_P5.00mm
C2: 0.1uF; CP_Radial_D8.0mm_P5.00mm
D1, D2, D3, D4, D5, D6, D7, D8, D9, D10: LED; D_A-405_P2.54mm_Vertical_AnodeUp
J1: 10132797-035100LF; 10132797035100LF; Manufacturer_Part_Number 10132797-035100LF; Mouser Part Number 649-10132797035100LF
J2: 10132797-015100LF; 10132797015100LF; Manufacturer_Part_Number 10132797-015100LF; Mouser Part Number 649-10132797015100LF
J3, J4: Conn_01x02_Male; PinHeader_1x02_P2.54mm_Vertical
J5: Conn_01x04_Male; PinHeader_1x04_P2.54mm_Vertical
J6: Conn_01x03_Male; PinHeader_1x03_P2.54mm_Vertical
R1, R2: 47K; R_0805_2012Metric_Pad1.20x1.40mm_HandSolder
R3: 100K; R_0805_2012Metric_Pad1.20x1.40mm_HandSolder
R4, R5, R6, R7, R8: 36; R_0805_2012Metric_Pad1.20x1.40mm_HandSolder
R9, R10: 100k; R_0805_2012Metric_Pad1.20x1.40mm_HandSolder
RV1: R_Potentiometer; PinHeader_1x03_P2.54mm_Vertical
TP1, TP2: TestPoint; TestPoint_Pad_3.0x3.0mm
U1: dfr0489
U2, U4: BSR802NL6327HTSA1; SOT95P285X135-3N; Mouser Part Number 726-BSR802NL6327HTSA
U3: mcp1407; SOIC-8_3.9x4.9mm_P1.27mm

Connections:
3.3V: J5.1, U1.17 (3V3)
+5V: C1.1, C2.1, J1.16, J1.17, J3.1, J4.2, RV1.1, TP2.1, U3.1 (VDD), U3.8 (VDD)
CDONE: J1.4
GND: C1.2, C2.2, J1.3, J1.5, J1.6, J1.7, J1.9, J2.5, J5.2, J6.3, R2.2, R3.2, R10.2, TP1.1, U1.15 (GND), U2.2 (S), U3.4 (GND), U3.5 (GND), U4.2 (S)
GPIO0: J1.30
GPIO1: J1.29, U3.2 (Input)
GPIO2: J1.28
GPIO3: J1.27
GPIO4: J1.26
GPIO5: J1.25
GPIO6: J1.24
GPIO7: J1.23
GPIO8: J1.2
IMU_INT: J1.20
LED_CHARGE: J1.8
LED_CRTL: R1.1, U1.6 (D5)
unnamed: D1.1 (K), D2.2 (A)
unnamed: D1.2 (A), R4.2
unnamed: D3.1 (K), D4.2 (A)
unnamed: D3.2 (A), R5.2
unnamed: D5.1 (K), D6.2 (A)
unnamed: D5.2 (A), R6.2
unnamed: D7.1 (K), D8.2 (A)
unnamed: D7.2 (A), R7.2
unnamed: D9.2 (A), R8.2
unnamed: D2.1 (K), D4.1 (K), D6.1 (K), D8.1 (K), D10.1 (K), U4.3 (D)
unnamed: D9.1 (K), D10.2 (A)
unnamed: J4.1, U2.3 (D)
unnamed: R1.2, R2.1, U2.1 (G)
unnamed: R3.1, U3.6 (OUT), U3.7 (OUT), U4.1 (G)
unnamed: R4.1, R5.1, R6.1, R7.1, R8.1, RV1.2
unnamed: J6.2, U1.10 (D9)
RGB_LED_IN: J1.22
RGB_LED_OUT: J1.1
SCL: J5.3, U1.25 (SCL)
SDA: J5.4, U1.26 (SDA)
SPI_CLK: J2.4
SPI_MISO: J2.2
SPI_MOSI: J2.3
VBAT: J3.2, J6.1, R9.1, U1.18 (VCC/VBAT)
iCE_RX: J1.10, U1.5 (D4)
iCE_TX: J1.11, U1.4 (D3)
~FLASH_CS: J2.1
~RESET: J2.6, U1.3 (D2)

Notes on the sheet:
Connectors to head
Screen Connector
IR Led control
/!\ IR_LED_3 : PB boot
We need to cut the power of the pogobot in order to program the esp8266
Visible LED control
ESP8266
+VBatt plugged to +5V when it's a standalone head (no battery to charge)

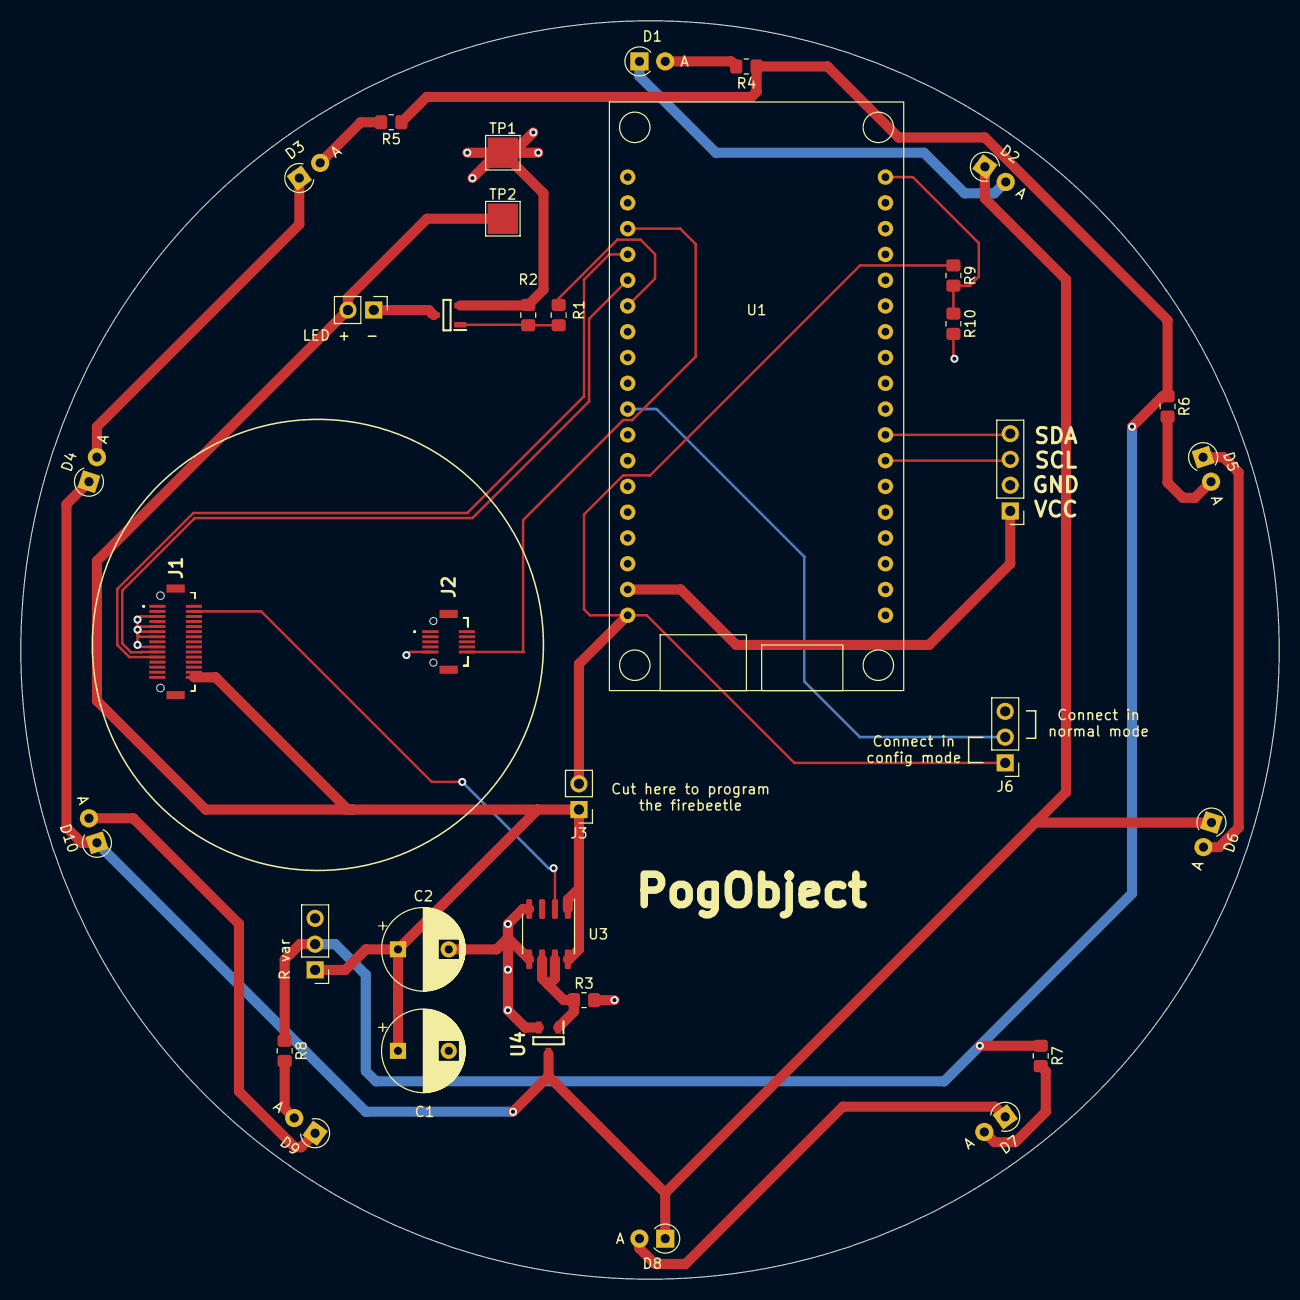
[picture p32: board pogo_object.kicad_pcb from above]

Board: 2 copper layers, 124.0 x 124.0 mm, 35 parts (0 on the bottom side), 27 nets.

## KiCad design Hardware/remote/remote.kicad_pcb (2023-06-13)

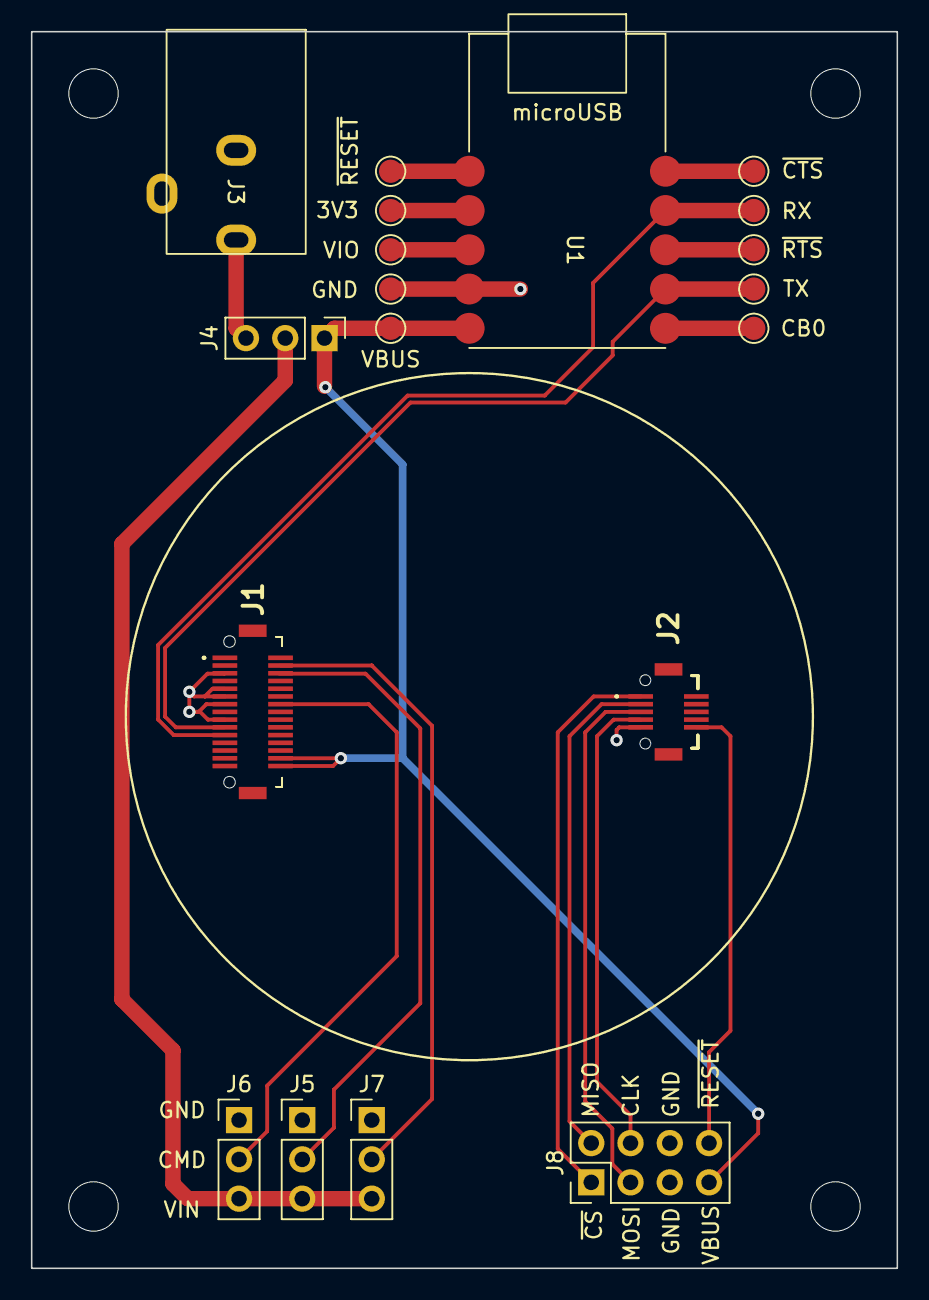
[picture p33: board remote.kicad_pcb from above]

Board: 2 copper layers, 56.0 x 80.0 mm, 16 parts (0 on the bottom side), 17 nets.

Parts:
3V3: TestPoint; TestPoint_Pad_D1.5mm
CB0: TestPoint; TestPoint_Pad_D1.5mm
GND: TestPoint; TestPoint_Pad_D1.5mm
J1: 10132797-035100LF; 10132797035100LF
J2: 10132797-015100LF; 10132797015100LF
J3: Barrel_Jack_Switch; Barrel Jack_SparkFun_PRT-10811
J4, J5, J6, J7: Conn_01x03_Male; PinHeader_1x03_P2.54mm_Vertical
J8: Conn_02x04_Counter_Clockwise; PinHeader_2x04_P2.54mm_Vertical
RX: TestPoint; TestPoint_Pad_D1.5mm
TX: TestPoint; TestPoint_Pad_D1.5mm
U1: umft234xf_module; umft234xf
VBUS: TestPoint; TestPoint_Pad_D1.5mm
VIO: TestPoint; TestPoint_Pad_D1.5mm

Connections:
+5V: J1.16, J1.17, J4.1, J8.7, U1.5 (VBUS), VBUS.1
GND: GND.1, J1.3, J1.5, J1.6, J1.7, J1.9, J2.5, J3.2, J3.3, J5.1, J6.1, J7.1, J8.5, J8.6, U1.4 (GND)
GPIO1: J1.29, J7.2
GPIO2: J1.28, J5.2
GPIO6: J1.24, J6.2
unnamed: 3V3.1, U1.2 (3V3)
unnamed: CB0.1, U1.6 (CB0)
unnamed: J3.1, J4.3
unnamed: U1.3 (VIO), VIO.1
SPI_CLK: J2.4, J8.4
SPI_MISO: J2.2, J8.2
SPI_MOSI: J2.3, J8.3
Vdrive: J4.2, J5.3, J6.3, J7.3
iCE_RX: J1.10, TX.1, U1.7 (TXD)
iCE_TX: J1.11, RX.1, U1.9 (RXD)
~FLASH_CS: J2.1, J8.1
~RESET: J2.6, J8.8

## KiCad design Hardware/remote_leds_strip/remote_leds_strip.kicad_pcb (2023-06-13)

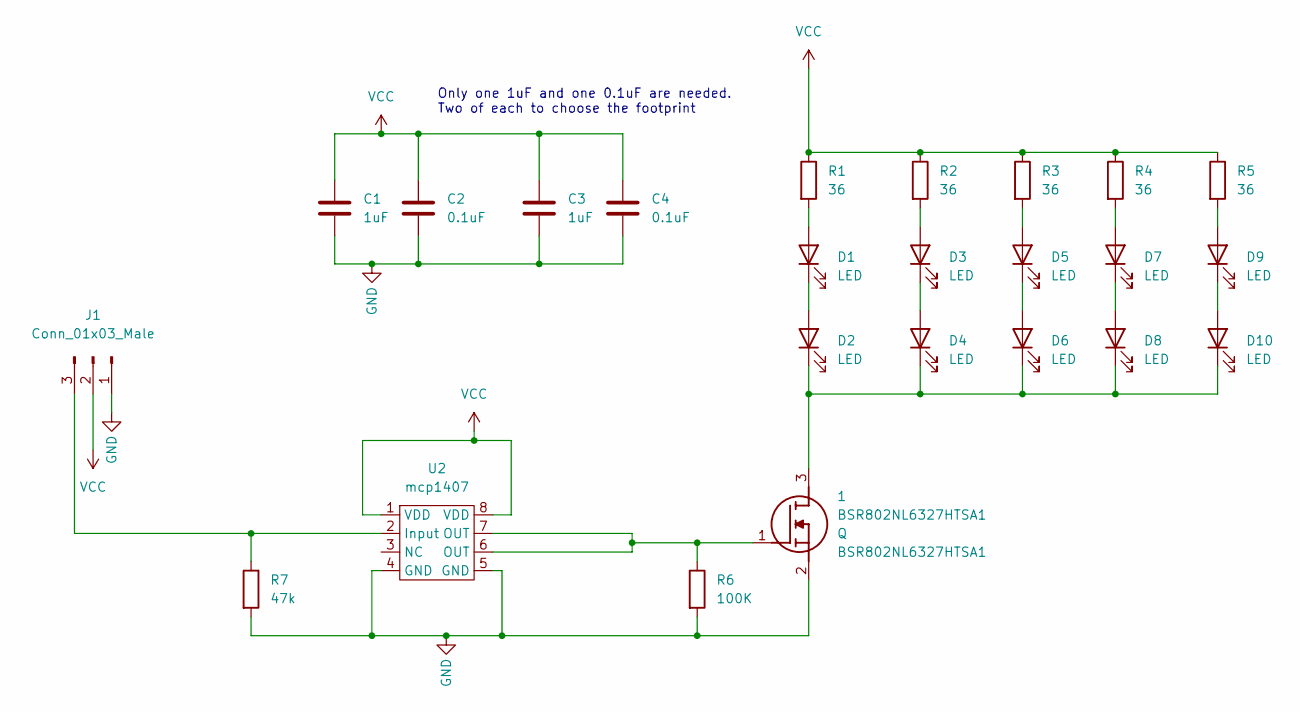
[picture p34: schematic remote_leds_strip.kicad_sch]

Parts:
1: BSR802NL6327HTSA1; SOT95P285X135-3N; Mouser Part Number 726-BSR802NL6327HTSA
C1: 1uF; C_0805_2012Metric_Pad1.18x1.45mm_HandSolder
C2: 0.1uF; C_0805_2012Metric_Pad1.18x1.45mm_HandSolder
C3: 1uF; CP_Radial_D5.0mm_P2.00mm
C4: 0.1uF; CP_Radial_D5.0mm_P2.00mm
D1, D2, D3, D4, D5, D6, D7, D8, D9, D10: LED; D_A-405_P2.54mm_Vertical_AnodeUp
J1: Conn_01x03_Male; PinHeader_1x03_P2.54mm_Vertical
R1, R2, R3, R4, R5: 36; R_0805_2012Metric_Pad1.20x1.40mm_HandSolder
R6: 100K; R_0805_2012Metric_Pad1.20x1.40mm_HandSolder
R7: 47k; R_0805_2012Metric_Pad1.20x1.40mm_HandSolder
U2: mcp1407; SOIC-8_3.9x4.9mm_P1.27mm

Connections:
GND: 1.2 (S), C1.2, C2.2, C3.2, C4.2, J1.1, R6.2, R7.2, U2.4 (GND), U2.5 (GND)
unnamed: D1.1 (K), D2.2 (A)
unnamed: D1.2 (A), R1.2
unnamed: D3.1 (K), D4.2 (A)
unnamed: D3.2 (A), R2.2
unnamed: D5.1 (K), D6.2 (A)
unnamed: D5.2 (A), R3.2
unnamed: D7.1 (K), D8.2 (A)
unnamed: D7.2 (A), R4.2
unnamed: D9.2 (A), R5.2
unnamed: 1.3 (D), D2.1 (K), D4.1 (K), D6.1 (K), D8.1 (K), D10.1 (K)
unnamed: D9.1 (K), D10.2 (A)
unnamed: J1.3, R7.1, U2.2 (Input)
unnamed: 1.1 (G), R6.1, U2.6 (OUT), U2.7 (OUT)
VCC: C1.1, C2.1, C3.1, C4.1, J1.2, R1.1, R2.1, R3.1, R4.1, R5.1, U2.1 (VDD), U2.8 (VDD)

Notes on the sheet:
Only one 1uF and one 0.1uF are needed. Two of each to choose the footprint

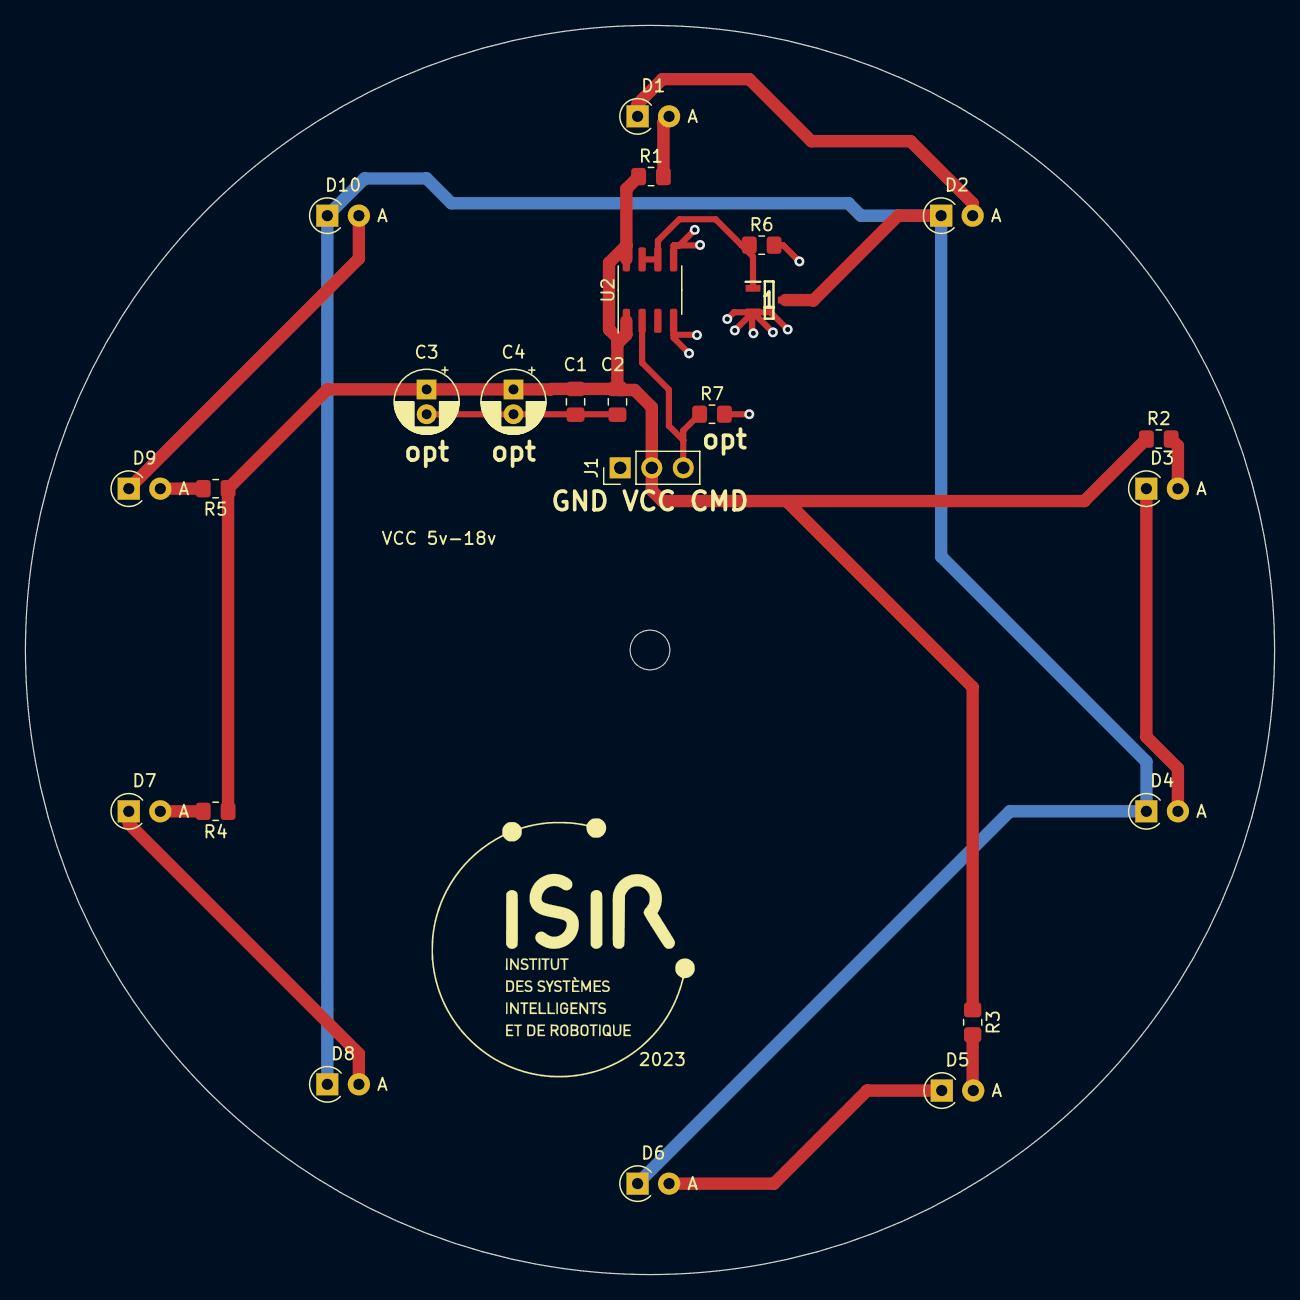
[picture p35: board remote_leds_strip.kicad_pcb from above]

Board: 2 copper layers, 100.7 x 100.7 mm, 24 parts (0 on the bottom side), 15 nets.

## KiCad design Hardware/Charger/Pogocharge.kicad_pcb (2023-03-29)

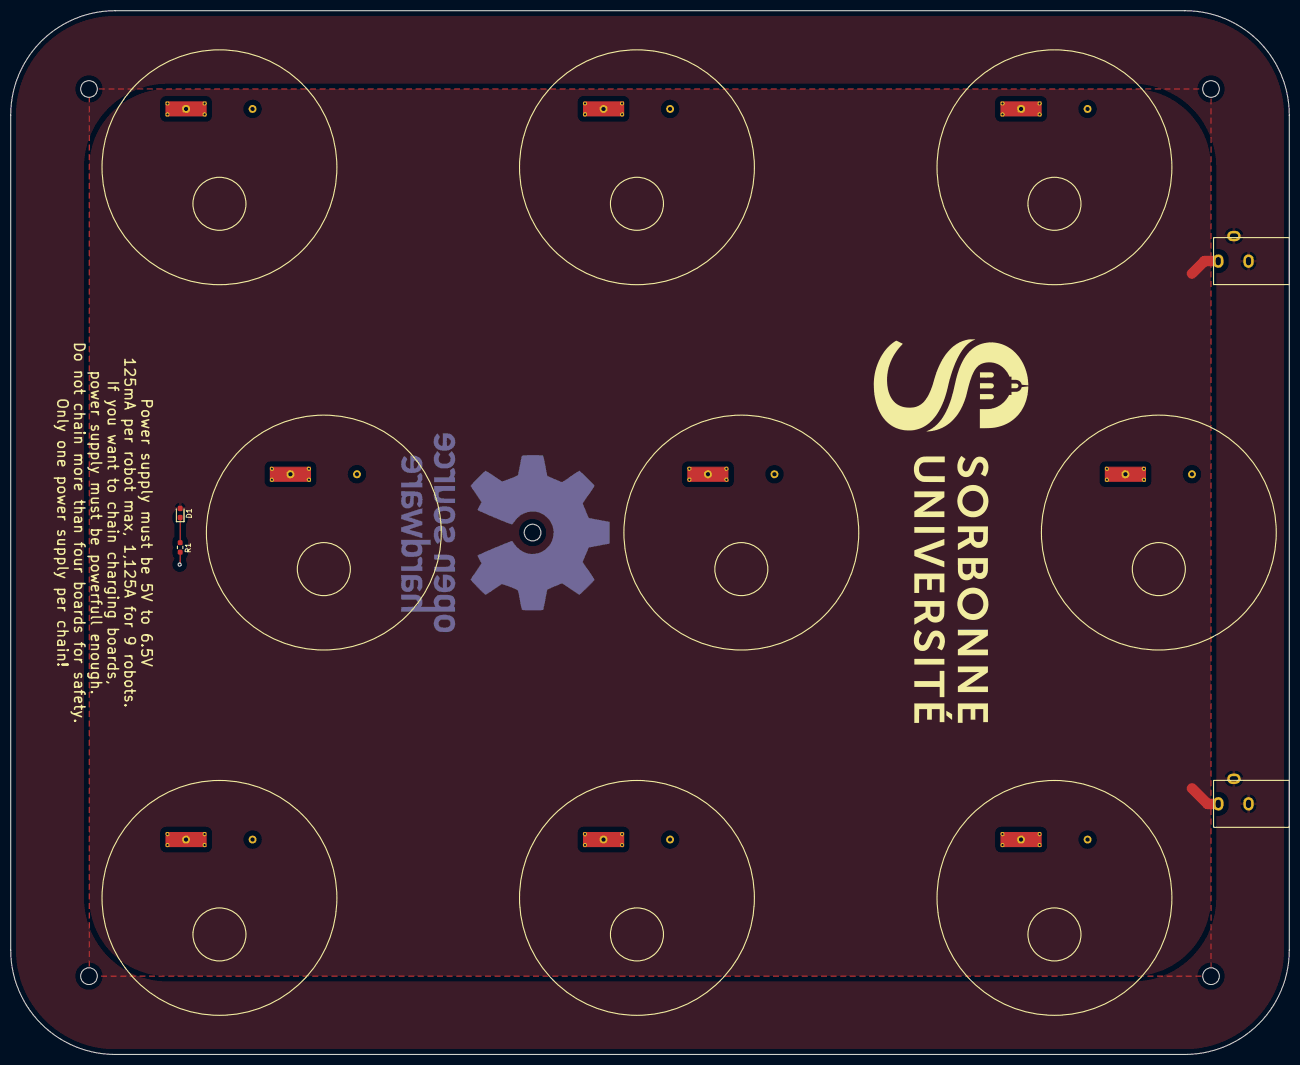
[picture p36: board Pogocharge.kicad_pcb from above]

Board: 2 copper layers, 245.0 x 200.0 mm, 22 parts (0 on the bottom side), 3 nets.

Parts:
D1: LED; LED_0603_1608Metric_Pad1.05x0.95mm_HandSolder
J1, J4: Barrel_Jack_Switch; Barrel Jack_SparkFun_PRT-10811
J6, J8, J9, J10, J11, J19, J20, J21, J22: 90224-AS; 90224-AS-plus
J12, J13, J15, J16, J17, J23, J24, J25, J26: 90224-AS; 90224-AS-minus
R1: 10k; R_0603_1608Metric_Pad0.98x0.95mm_HandSolder

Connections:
+5V: D1.2 (A), J1.1, J4.1
GND: J1.2, J1.3, J4.2, J4.3, J12.1, J13.1, J15.1, J16.1, J17.1, J23.1, J24.1, J25.1, J26.1, R1.2
unnamed: D1.1 (K), R1.1

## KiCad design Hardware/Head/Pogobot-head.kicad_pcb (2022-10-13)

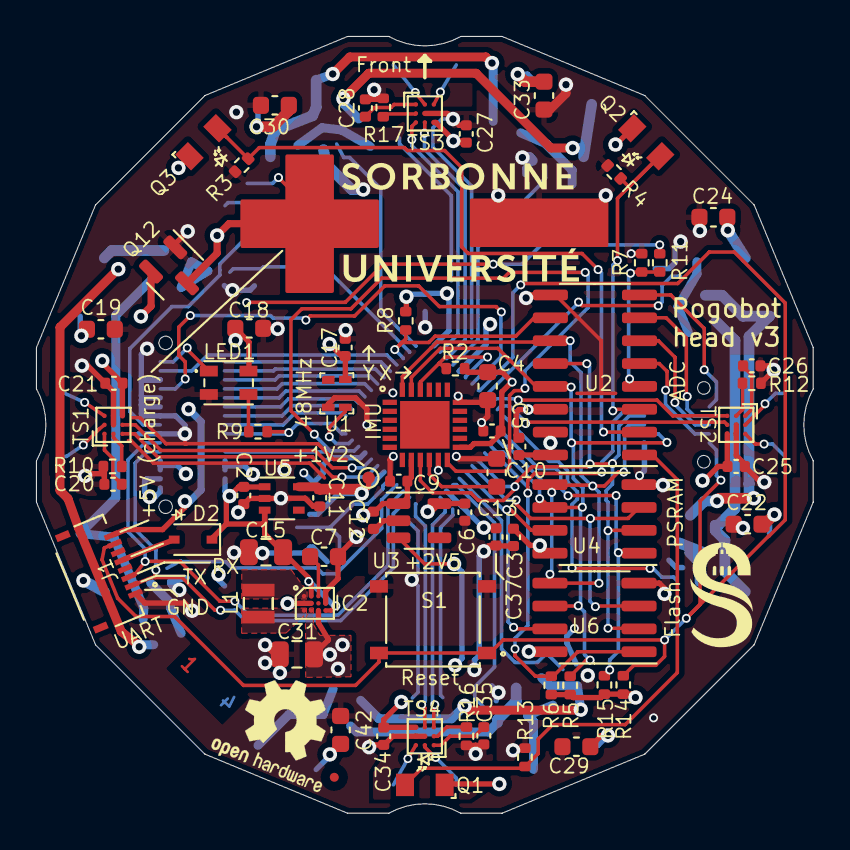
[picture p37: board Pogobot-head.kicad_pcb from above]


Board: 4 copper layers, 43.2 x 43.2 mm, 136 parts (64 on the bottom side), 98 nets.

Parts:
C1, C2, C5, C6, C11, C12, C14, C20, C26, C28, C35: 1uF; C_0402_1005Metric
C3, C16, C17, C37, C38, C39, C40, C41: 100nF; C_0402_1005Metric
C4: 2.2uF, X5R; C_0603_1608Metric
C7: 1uF, 10V; C_0603_1608Metric
C8, C32: 10nF; C_0402_1005Metric
C9: 10nF, X7R; C_0402_1005Metric
C10, C21, C25, C27, C34: 100nF, X7R; C_0402_1005Metric
C13: 470nF, X7R; C_0603_1608Metric
C15: 10uF, 10V; C_0805_2012Metric
C18, C36: 10uF; C_0603_1608Metric
C19, C22, C23, C24, C29, C30, C33, C42: 10uF, 6V; C_0603_1608Metric
C31: 22uF, 6V; C_0805_2012Metric
D2: 1N4448WS; D_SOD-323
D3, D8, D13, D14: VEMD10940F; VEMD10940FX01
D4, D5, D6, D7, D9, D10, D11, D12: VSMB10940
D15: LED; LED_0603_1608Metric_Pad1.05x0.95mm_HandSolder
IC1: ICM-20689; QFN50P400X400X95-25N-D
IC2: MAX77827DEWC+T; BGA12C40P4X3_201X161X69
J1: 2328702-8; 23287028
J3: 10132798-032100LF; 10132798032100LF
J5: 10132798-012100LF; 10132798012100LF
L1: MEKK2016H1R0M 1.0uH 41mOhms 4.5A; MEKK2016H
LED1: IN-PI22TAT5R5G5B; INPI22TAT5R5G5B
LOGO01: OSHW-Logo2_7.3x6mm_SilkScreen
LOGO02: KiCad-Logo2_5mm_SilkScreen
LOGO03: LOGO; LOGO_SU_without_text
LOGO04: LOGO; logo_isir_moyen
Q1, Q2, Q3: SFH 3710-Z; SFH3710
Q4, Q5, Q6, Q7, Q8, Q9, Q10, Q11: NTK3134NT5G; SOT-723
Q12: Q_PMOS_GSD; SOT-23
R2, R5, R6, R7, R8, R11, R14, R15, R24, R25, R28, R29, R31, R33, R36, R41: 10K; R_0402_1005Metric
R3, R4, R13: 1M; R_0402_1005Metric
R9: 330; R_0402_1005Metric
R10, R12, R16, R17: 15K; R_0402_1005Metric
R18, R19, R20, R26, R32, R37, R38, R39: 3; R_0603_1608Metric
R21, R22, R23, R27, R34, R35, R40, R42: 6; R_0603_1608Metric
R30: 100; R_0402_1005Metric
R43: 1K; R_0603_1608Metric
S1: PTS526_SM15_SMTR2_LFS; PTS526SK15SMTR2LFS
TP1: Testpoint; TestPoint_Pad_D0.7mm
TP2: TestPoint; Plus
TP3: TestPoint; Minus
TS1, TS2, TS3, TS4: TS4231; BGA-9_1.6x1.6mm_Layout3x3_P0.5mm
U1: DSC6101MI2B-048.0000; 4-Lead 2.0 mm x 1.6 mm VFLGA
U2: MCP3008; SOIC-16_3.9x9.9mm_P1.27mm
U3: MIC5504-2.5YM5; SOT-23-5
U4: LY68L6400; SOIC-8_3.9x4.9mm_P1.27mm
U5: MIC5365-1.2YC5; SOT-353_SC-70-5
U6: W25Q16JVSNIM; SOIC-8_3.9x4.9mm_P1.27mm
U7: ICE40UP5K-SG48; QFN-48-1EP_7x7mm_P0.5mm_EP5.3x5.3mm

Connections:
+1V2: C1.1, C8.1, C11.1, C14.1, C16.1, C32.1, C38.1, R30.2, TP1.1, U3.3 (EN), U5.5 (VOUT), U7.5 (VCC), U7.30 (VCC)
+2V5: C6.1, U3.5 (VOUT), U7.24 (VPP_2V5)
+3V3: C3.1, C4.1, C5.1, C9.1, C10.1, C12.1, C17.1, C18.1, C19.1, C21.1, C22.1, C23.1, C24.1, C25.1, C27.1, C29.1, C30.1, C31.1, C33.1, C34.1, C37.1, C40.1, C41.1, C42.1, D4.2, D5.2, D6.2, D7.2, D9.2, D10.2, D11.2, D12.2, IC1.8 (VDDIO), IC1.13 (VDD), IC2.C2 (OUT), IC2.C3 (OUTS), J3.12, J3.13, J3.18, J3.19, LED1.4 (VDD), Q1.1 (C), Q2.1 (C), Q3.1 (C), R2.1, R5.1, R6.1, R8.1, R14.1, R15.1, TS1.C3 (DVDD), TS2.C3 (DVDD), TS3.C3 (DVDD), TS4.C3 (DVDD), U1.4 (VDD), U2.15 (Vref), U2.16 (Vdd), U3.1 (VIN), U4.8 (VCC), U6.8 (VCC), U7.1 (VCCIO_2), U7.22 (SPI_VCCIO1), U7.33 (VCCIO_0)
+5V: J3.14, J3.15, Q12.2 (S)
+BATT: C2.1, C15.1, D2.1 (K), IC2.A2 (IN), IC2.C4 (EN), J3.16, J3.17, R11.1, U5.1 (VIN), U5.3 (EN)
/Back: Q1.2 (E), R13.1, U2.1 (CH0)
/CH4: J5.7, U2.5 (CH4)
/CH5: J5.8, U2.6 (CH5)
/CH6: J5.9, U2.7 (CH6)
/CH7: J5.10, U2.8 (CH7)
/Charge: D15.2 (A), J1.8, Q12.3 (D), TP2.1
/LX1: IC2.A1 (LX1), L1.2
/LX2: IC2.C1 (LX2), L1.1
/Left: Q3.2 (E), R3.1, U2.2 (CH1)
/OSC_IN: U1.3 (OUT), U7.35 (IOT_46B_G0)
/Right: Q2.2 (E), R4.1, U2.3 (CH2)
/VBat_control: R7.1, R11.2, U2.4 (CH3)
/VCCPLL: C36.1, C39.1, R30.1, U7.29 (VCCPLL)
/sheetReceive_Back/AVDD: C35.1, TS4.A1 (AVDD)
/sheetReceive_Back/IIN+: D14.2 (A), TS4.A2 (IIN+)
/sheetReceive_Back/IIN-: D14.1 (K), TS4.A3 (IIN-)
/sheetReceive_Back/RBIAS: R16.2, TS4.B1 (RBIAS)
/sheetReceive_Front/AVDD: C28.1, TS3.A1 (AVDD)
/sheetReceive_Front/IIN+: D13.2 (A), TS3.A2 (IIN+)
/sheetReceive_Front/IIN-: D13.1 (K), TS3.A3 (IIN-)
/sheetReceive_Front/RBIAS: R17.2, TS3.B1 (RBIAS)
/sheetReceive_Left/AVDD: C20.1, TS1.A1 (AVDD)
/sheetReceive_Left/IIN+: D8.2 (A), TS1.A2 (IIN+)
/sheetReceive_Left/IIN-: D8.1 (K), TS1.A3 (IIN-)
/sheetReceive_Left/RBIAS: R10.2, TS1.B1 (RBIAS)
/sheetReceive_Right/AVDD: C26.1, TS2.A1 (AVDD)
/sheetReceive_Right/IIN+: D3.2 (A), TS2.A2 (IIN+)
/sheetReceive_Right/IIN-: D3.1 (K), TS2.A3 (IIN-)
/sheetReceive_Right/RBIAS: R12.2, TS2.B1 (RBIAS)
ADC_CSn: R8.2, U2.10 (~CS/SHDN), U7.46 (IOB_0A)
CDONE: J3.4, U7.7 (CDONE)
Emit1_B: Q10.1 (G), R31.1, U7.20 (IOB_25B_G3)
Emit1_F: Q9.1 (G), R33.1, U7.48 (IOB_4A)
Emit1_L: Q4.1 (G), R24.1, U7.47 (IOB_2A)
Emit1_R: Q5.1 (G), R25.1, U7.12 (IOB_22A)
Emit2_B: Q8.1 (G), R36.1, U7.21 (IOB_23B)
Emit2_F: Q11.1 (G), R41.1, U7.4 (IOB_8A)
Emit2_L: Q7.1 (G), R29.1, U7.28 (IOT_41A)
Emit2_R: Q6.1 (G), R28.1, U7.9 (IOB_16A)
FLASH_CS: J5.1, R6.2, U6.1 (~CS), U7.16 (IOB_35b_SPI_CSN)
GND: C1.2, C2.2, C3.2, C4.2, C5.2, C6.2, C7.2, C8.2, C9.2, C10.2, C11.2, C12.2, C13.2, C14.2, C15.2, C16.2, C17.2, C18.2, C19.2, C20.2, C21.2, C22.2, C23.2, C24.2, C25.2, C26.2, C27.2, C28.2, C29.2, C30.2, C31.2, C32.2, C33.2, C34.2, C35.2, C36.2, C37.2, C38.2, C39.2, C40.2, C41.2, C42.2, IC1.11 (FSYNC), IC1.18 (GND), IC2.A4 (AGND), IC2.B1 (PGND), IC2.B2 (FPWM), IC2.B4 (SEL), J1.1, J3.3, J3.5, J3.6, J3.7, J3.9, J5.5, J5.MP2, LED1.2 (VSS), Q4.2 (S), Q5.2 (S), Q6.2 (S), Q7.2 (S), Q8.2 (S), Q9.2 (S), Q10.2 (S), Q11.2 (S), Q12.1 (G), R3.2, R4.2, R7.2, R10.1, R12.1, R13.2, R16.1, R17.1, R24.2, R25.2, R28.2, R29.2, R31.2, R33.2, R36.2, R41.2, S1.3 (NO_1), S1.4 (NO_2), TP3.1, TS1.B2 (AVSS), TS1.B3 (AVSS2), TS2.B2 (AVSS), TS2.B3 (AVSS2), TS3.B2 (AVSS), TS3.B3 (AVSS2), TS4.B2 (AVSS), TS4.B3 (AVSS2), U1.2 (GND), U2.9 (DGND), U2.14 (AGND), U3.2 (GND), U4.4 (VSS), U5.2 (GND), U6.4 (GND), U7.49 (PAD/GND)
GPIO0: J3.30, U7.44 (IOB_3B_G6)
GPIO1: J3.29, U7.43 (IOT_49A)
GPIO2: J3.28, U7.42 (IOT_51A)
GPIO3: J3.27, U7.41 (RGB2)
GPIO4: J3.26, U7.40 (RGB1)
GPIO5: J3.25, U7.39 (RGB0)
GPIO6: J3.24, U7.38 (IOT_50B)
GPIO7: J3.23, U7.37 (IOT_45A_G1)
GPIO8: J3.2, U7.45 (IOB_5B)
IMU_CSn: IC1.22 (NCS), R2.2, U7.6 (IOB_13B)
IMU_INT: IC1.12 (INT), J3.20, U7.34 (IOT_44B)
LED_CHARGE: J3.8, R43.2
unnamed: C7.1, IC2.A3 (BIAS)
unnamed: C13.1, IC1.10 (REGOUT)
unnamed: D2.2 (A), J1.5
unnamed: D4.1, R18.1, R27.1
unnamed: D5.1, R20.1, R22.1
unnamed: D6.1, R19.1, R21.1
unnamed: D7.1, R23.1, R26.1
unnamed: D9.1, R35.1, R38.1
unnamed: D10.1, R32.1, R40.1
unnamed: D11.1, R34.1, R39.1
unnamed: D12.1, R37.1, R42.1
unnamed: D15.1 (K), R43.1
unnamed: LED1.3 (DIN), R9.1
unnamed: Q4.3 (D), R23.2, R27.2
unnamed: Q5.3 (D), R21.2, R22.2
unnamed: Q6.3 (D), R19.2, R20.2
unnamed: Q7.3 (D), R18.2, R26.2
unnamed: Q8.3 (D), R38.2, R39.2
unnamed: Q9.3 (D), R40.2, R42.2
unnamed: Q10.3 (D), R34.2, R35.2
unnamed: Q11.3 (D), R32.2, R37.2
RAM_CS: R15.2, U4.1 (~CE), U7.13 (IOB_24A)
RGB_LED_IN: J3.22, R9.2, U7.36 (IOT_48B)
RGB_LED_OUT: J3.1, LED1.1 (DOUT)
SPI_CLK: IC1.23 (SCL/SCLK), J5.4, R5.2, U2.13 (CLK), U4.6 (SCLK), U6.6 (CLK), U7.15 (IOB_34a_SPI_SCK)
SPI_MISO: IC1.9 (AD0/SDO), J5.2, U2.12 (Dout), U4.2 (SO/SIO), U6.2 (DO/IO1), U7.17 (IOB_33b_SPI_SI)
SPI_MOSI: IC1.24 (SDA/SDI), J5.3, U2.11 (Din), U4.5 (SI/SIO), U6.5 (DI/IO0), U7.14 (IOB_32a_SPI_SO)
SPI_~HLD-IO3: U4.7 (SIO3), U6.7 (~HLD/~RST/IO3), U7.19 (IOB_29B)
SPI_~WP-IO2: U4.3 (SIO2), U6.3 (~WP/IO2), U7.18 (IOB_31B)
TSDATA_B: TS4.C1 (D), U7.23 (IOT_37A)
TSDATA_F: TS3.C1 (D), U7.2 (IOB_6A)
TSDATA_L: TS1.C1 (D), U7.31 (IOT_42B)
TSDATA_R: TS2.C1 (D), U7.10 (IOB_18A)
TSENV_B: TS4.C2 (E), U7.25 (IOT_36B)
TSENV_F: TS3.C2 (E), U7.3 (IOB_9B)
TSENV_L: TS1.C2 (E), U7.32 (IOT_43A)
TSENV_R: TS2.C2 (E), U7.11 (IOB_20A)
iCE_RX: J1.3, J3.10, U7.27 (IOT_38B)
iCE_TX: J1.2, J3.11, U7.26 (IOT_39A)
~RESET: J1.7, J5.6, R14.2, S1.1 (COM_1), S1.2 (COM_2), U7.8 (CRESET_B)

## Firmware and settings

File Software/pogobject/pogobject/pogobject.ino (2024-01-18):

/*
 * Pogobot Object
 * 
 * Tested with the arduino IDE 1.8.13
 * this code is the fusion of example from the libraries
 * - aREST (https://github.com/marcoschwartz/aREST v2.9.7)
 * - SoftwareSerial
 * - dfRobot u8g2 (https://github.com/olikraus/u8g2 v2.27.2)
 * - board library FireBeetle-ESP8266 (https://raw.githubusercontent.com/DFRobot/FireBeetle-ESP8266/master/package_firebeetle8266_index.json v2.3.3)
 * 
 * Code realized for a FireBeetle ESP8266 (DRF0489), 0.91" oled screen I2C (DFR0647), pogobot v3 
 * 
 * Pinout :
 * pogobot
 * D3 -> TX pogobot
 * D4 -> RX pogobot
 * D2 -> RESET pogobot
 * VCC -> Bat pogobot
 * GND -> GND pogobot
 * 
 * exterior Leds 
 * D5 -> PWM to control a LED intensity
 * 
 * screen in 3.3V
 * standard  I2C connexion
 * 
 * battery verification
 * voltage divider between VCC - A0 - GND (2*100kOhms) 
 *
 * configuration du wifi
 * pin D9 to GND -> normal mode
 * pin D9 to VCC -> configuration mode
 * 
 * The SSID can only make 32 caracters
 * The password is only 64 caracters
 * 
 */

#include <Arduino.h>
// aREST
#include <ESP8266WiFi.h>
#include <aREST.h>
// Screen
#include <U8g2lib.h>
#include <Wire.h>
// Software Serial
#include "SoftwareSerial.h"
// Wifi configuration
#include <ESP8266WebServer.h>
#include <EEPROM.h>

//screen variables
U8G2_SSD1306_128X32_UNIVISION_F_HW_I2C u8g2(U8G2_R0, /* reset=*/ U8X8_PIN_NONE); 

// WiFi configuration parameters
const char* defaultSSID = "PogobjectConfig";
const char* defaultPassword = "pogobotconfig";

// Global ssid / password value used
char ssid[32]; 
char password[64]; 

// Create an instance of a WebServer for configuration
ESP8266WebServer server_config(80);

// Check Battery voltage using multimeter & add/subtract the value
float calibration = 0.64; 

// The port to listen for incoming TCP connections
#define LISTEN_PORT 80

// Create an instance of the server
WiFiServer server(LISTEN_PORT);

// Create aREST instance
aREST rest = aREST();

// Variables to be exposed to the API
String IPaddr;
int led_on = 0;
int bat_percentage = 0;
float voltage = 0;

// Pin Definition
#define RX D3 // -> TX pogobot
#define TX D4 // -> RX pogobot
#define RESET_P D2 // -> RESET pogobot
#define LED_PIN D5 // -> PWM for Led control
#define CONFIG_PIN D9 // put to vcc to start configuration 

// software serial definition
#define BAUD_RATE 115200
SoftwareSerial swSerial(RX, TX);

// aREST
// Declare functions to be exposed to the API
int CmdControl(String command);
int ledControl(String command);
int reboot_p(String command);
int update_bat_percent(String command);

// author apicquot from https://forum.arduino.cc/index.php?topic=228884.0
String IpAddress2String(const IPAddress& ipAddress)
{
    return String(ipAddress[0]) + String(".") +
           String(ipAddress[1]) + String(".") +
           String(ipAddress[2]) + String(".") +
           String(ipAddress[3]);
}

// general function to print on the screen
void printScreen(String text)
{
    u8g2.clearBuffer();          // clear the internal memory
    u8g2.setFont(u8g2_font_ncenB08_tr); // choose a suitable font
    u8g2.drawStr(0,30,text.c_str());  // write something to the internal memory
    u8g2.drawStr(0,10,IPaddr.c_str());  // write something to the internal memory
    u8g2.sendBuffer();          // transfer internal memory to the display
    delay(1000);
    Serial.println(text);
} 

// from https://github.com/radishlogic/MapFloat/blob/master/src/MapFloat.cpp
float mapFloat(float value, float fromLow, float fromHigh, float toLow, float toHigh) {
  return (value - fromLow) * (toHigh - toLow) / (fromHigh - fromLow) + toLow; 
}

void handleRoot() {
  String html = "<html><head><style>";
  html += "body {font-family: Arial, sans-serif; margin: 50px;}";
  html += "h1 {color: #333; text-align: center;}";
  html += "form {max-width: 400px; margin: auto;}";
  html += "input {width: 100%; padding: 10px; margin: 5px 0;}";
  html += "input[type=submit], input[type=button] {background-color: #B7B7B7; color: white;}";
  html += "</style></head><body>";
  html += "<h1>Configuration WiFi</h1>";
  html += "<form action='/configure' method='post'>";
  html += "SSID: <input type='text' name='ssid' value='" + String(ssid) + "' required><br>";
  html += "Mot de passe: <input type='password' name='password' id='password' value='" + String(password) + "' required>";
  html += "<input type='button' value='Afficher le mot de passe' onclick='togglePasswordVisibility()'><br>";
  html += "<input type='submit' value='Configurer'>";
  html += "</form>";
  html += "<script>";
  html += "function togglePasswordVisibility() {";
  html += "  var passwordInput = document.getElementById('password');";
  html += "  if (passwordInput.type === 'password') {";
  html += "    passwordInput.type = 'text';";
  html += "  } else {";
  html += "    passwordInput.type = 'password';";
  html += "  }";
  html += "}";
  html += "</script>";
  html += "</body></html>";

  server_config.send(200, "text/html", html);
}

void handleConfigure() {
  String newSSID = server_config.arg("ssid");
  String newPassword = server_config.arg("password");

  // update WIFI information
  newSSID.toCharArray(ssid, sizeof(ssid));
  newPassword.toCharArray(password, sizeof(password));

  // WRITE info to EEPROM 
  writeWiFiCredentials();

  // Html response
  String response = "<html><body>";
  response += "<h1>Wifi info updated with success</h1>";
  response += "<p>Please move D9 to 0, the pogobect will restart now...</p>";
  response += "</body></html>";

  server_config.send(200, "text/html", response);

  delay(4000);
  ESP.restart();
}

void readWiFiCredentials() {
  EEPROM.begin(512);

  // READ EEPROM for SSID
  for (int i = 0; i < sizeof(ssid); ++i) {
    ssid[i] = EEPROM.read(i);
  }

  // READ EEPROM for password
  for (int i = 0; i < sizeof(password); ++i) {
    password[i] = EEPROM.read(sizeof(ssid) + i);
  }

  EEPROM.end();
}

void writeWiFiCredentials() {
  EEPROM.begin(512);

  // WRITE new ssid to EEPROM
  for (int i = 0; i < sizeof(ssid); ++i) {
    EEPROM.write(i, ssid[i]);
  }

  // WRITE new password to EEPROM
  for (int i = 0; i < sizeof(password); ++i) {
    EEPROM.write(sizeof(ssid) + i, password[i]);
  }

  EEPROM.commit();
  EEPROM.end();
}

void setup(void) {

  // Start Serial
  Serial.begin(BAUD_RATE);
  Serial.println("\n Starting");
  Serial.print("ESP Board MAC Address:  ");
  Serial.println(WiFi.macAddress());

  // Start screen
  u8g2.begin();

  // wifi credentials
  readWiFiCredentials();
  Serial.print("Memorized credentials : ");
  Serial.print(ssid);
  Serial.print(" , ");
  Serial.println(password);

  // look for config Pin
  pinMode(CONFIG_PIN, INPUT);
  int config_mode = digitalRead(CONFIG_PIN); 

  if (config_mode) { // 1 means start configuration
    //Start AP mode
    Serial.print("Setting wifi mode ... ");
    Serial.println(WiFi.mode(WIFI_AP) ? "Ready" : "Failed!");
    Serial.print("Setting soft-AP ... ");
    Serial.println(WiFi.softAP(defaultSSID, defaultPassword) ? "Ready" : "Failed!");

    Serial.print("Soft-AP IP address = ");
    Serial.println(WiFi.softAPIP());

    // print IP to screen
    IPaddr = IpAddress2String(WiFi.softAPIP());
    u8g2.clearBuffer();          // clear the internal memory
    u8g2.setFont(u8g2_font_ncenB08_tr); // choose a suitable font
    u8g2.drawStr(0,10,IPaddr.c_str());  // write something to the internal memory
    u8g2.sendBuffer();          // transfer internal memory to the display
    delay(1000);
    printScreen("Config mode");

    // Start config server
    server_config.on("/", HTTP_GET, handleRoot);
    server_config.on("/configure", HTTP_POST, handleConfigure);
    server_config.begin();

    while (1) {
      server_config.handleClient();
    }

  }

  printScreen("Waiting for wifi");


  // pin mode definition
  pinMode(LED_PIN, OUTPUT);
  pinMode(RESET_P, OUTPUT);

  // Wifi connection
  WiFi.begin(ssid, password);
  while (WiFi.status() != WL_CONNECTED) {
    delay(500);
  }

  printScreen("Wifi ok");
  Serial.println("\n Wifi connected");
  
  // Start the server
  server.begin();

  // Print the IP address
  Serial.println(WiFi.localIP());

  // Print the IP address on  the screen
  IPaddr = IpAddress2String(WiFi.localIP());
  u8g2.clearBuffer();          // clear the internal memory
  u8g2.setFont(u8g2_font_ncenB08_tr); // choose a suitable font
  u8g2.drawStr(0,10,IPaddr.c_str());  // write something to the internal memory
  u8g2.sendBuffer();          // transfer internal memory to the display
  delay(1000);  

  //Check Battery
  update_bat_percent("none");
  Serial.println(bat_percentage);

  // Init variables and expose them to REST API
  rest.variable("IPaddr",&IPaddr);
  rest.variable("LedOn",&led_on);
  rest.variable("bat_percentage",&bat_percentage);
  rest.variable("bat_voltage",&voltage);

  // Function to be exposed
  // http://X.X.X.X/cmd?params=cmd  -> all cmd (without ", spaces are understand) compabible with the pogobot "auto_test led" for example
  // allows to send a cmd to the pogobot though the UART prompt
  rest.function((char*)"cmd",CmdControl);
  // http://X.X.X.X/led?params=Y  -> Y [0:1024]
  // allows to change the pwm ratio of the pin "LED_PIN"
  rest.function((char*)"led",ledControl);
  // http://X.X.X.X/reboot_p 
  // alows to reboot the pogobot for whatever is needed  
  rest.function((char*)"reboot_p",reboot_p);
  // http://X.X.X.X/read_bat 
  // update the battery reading 
  rest.function((char*)"read_bat",update_bat_percent);

  // Give name & ID to the device (ID should be 6 characters long)
  rest.set_id("1"); // Allows to give a unique ID to the pogobot object
  rest.set_name((char*)"pogObject");

  // Start the Software Serial to communicate with the pogobot
  swSerial.begin(BAUD_RATE);
  
  // keep pogobot alive
  digitalWrite(RESET_P,HIGH);
  
}

void loop(void) {

  //Check Battery
  //update_bat_percent();

  // Handle REST calls
  WiFiClient client = server.available();
  if (!client) {
    return;
  }
  while(!client.available()){
    delay(100);
  }
  rest.handle(client);

}

// function executed when a cmd on the pogobot is asked
int CmdControl(String command) {

  //print on screen
  printScreen(command);
  
  //send by serial
  swSerial.print(command+"\n");
  
  return 1;
}


// function to recover the battery voltage
int update_bat_percent(String command) {
  //recover sensor value
  int sensorValue = analogRead(A0);
  //multiply by two as voltage divider network is 100K & 100K Resistor
  voltage = (((sensorValue * 3.3) / 1024) * 2 + calibration); 
  //2.8V as Battery Cut off Voltage & 4.2V as Maximum Voltage
  bat_percentage = mapFloat(voltage, 3.0, 4.2, 0, 100); 

  return 1;
}

// function executed when the led pwm is changed
int ledControl(String command) {

  // Get state from command
  int state = command.toInt();
  led_on = state;
  analogWrite(LED_PIN,state);

  String text = "led at : " + command;
  printScreen(text);
  
  return 1;
}

// function executed when a reboot of the pogobot is asked
int reboot_p(String command) {

  // reboot command
  digitalWrite(RESET_P,LOW);
  delay(1000);
  digitalWrite(RESET_P,HIGH);

  printScreen("reboot pogobot");
  
  return 1;
}

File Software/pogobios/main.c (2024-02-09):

/**
 * POGOBOT
 *
 * Copyright © 2022 Sorbonne Université ISIR
 * This file is licensed under the Expat License, sometimes known as the MIT License.
 * Please refer to file LICENCE for details.
**/


#include <stdio.h>
#include <stdlib.h>
#include <stdint.h>
#include <console.h>
#include <string.h>
#include <uart.h>
#include <system.h>
#include <irq.h>
#include <init.h>
#include <ctype.h> 

#include <command.h>
#include <helpers.h> // get_param
#include <readline.h>
#include <memtest.h>
#include <ir_boot.h>
#include <boot.h>
#include <sfl.h>
#include <spiflash.h>

#include <pogobot.h>

#define QUOTE(str) #str
#define EXPAND_AND_QUOTE(str) QUOTE(str)

#ifdef REMOCON
#define POGOPROMPT "\e[92;1mRemoteControl\e[0m> "
#else
#if( ROM_BASE == (SPIFLASH_BASE + 0x20000) )
#define POGOPROMPT "\e[92;1mPogoboot\e[0m> "
#else
#define POGOPROMPT "\e[92;1mPogobot\e[0m> "
#endif
#endif

// Standby option status
uint8_t standby_status = 0; // 0 : OFF, 1 : ON LISTENING, 2 : ON SAVE ENERGY
uint8_t standby_reloaded = 0; // to check if the listening has begin (0 if is needed to reload the timer )
// Voltage status
uint8_t voltage_status = 0; // 0 : OFF, 1 : DISPLAY VOLTAGE
// Autotest status
uint8_t autotest_status = 0; // 0 : OFF, 1 : DISPLAY AUTOTEST RESULT
// Autotest done
uint8_t autotest_done = 0; // 0 : NO, 1 : YES

int main(void) {
    char buffer[CMD_LINE_BUFFER_SIZE];
    char *params[MAX_PARAM];
    char *command;
    struct command_struct *cmd;
    int nb_params;
    extern uint64_t unique_id, serial_number;

    pogobot_init(); // Needed for printf() (interrupts), slip, ...

    printf("\n");
    printf("\e[1m     ____                   _           _         \e[0m\n");
    printf("\e[1m    |  _ \\ ___   __ _  ___ | |__   ___ | |_      \e[0m\n");
    printf("\e[1m    | |_) / _ \\ / _` |/ _ \\| '_ \\ / _ \\| __|  \e[0m\n");
    printf("\e[1m    |  __/ (_) | (_| | (_) | |_) | (_) | |_       \e[0m\n");
    printf("\e[1m    |_|   \\___/ \\__, |\\___/|_.__/ \\___/ \\__| \e[0m\n");
    printf("\e[1m                 |___/                            \e[0m\n");
    printf("\e[1m    https://pogobot.github.io                     \e[0m\n");
    printf("\n");

    printf(" Licensed under the MIT License (also known as Expat License).\n");

    printf(" (c) Copyright 2022-2023 Sorbonne Université, Institut des Systèmes Intelligents et de Robotique (ISIR)\n");
    printf(" (c) Copyright 2012-2022 Enjoy-Digital\n");
    printf(" (c) Copyright 2007-2015 M-Labs\n");
    printf(" Work funded by the Agence Nationale pour la Recherche (ANR-18-CE33-0006).\n");
    printf("\n");

#ifdef CONFIG_WITH_BUILD_TIME
    printf(" BIOS built on "__DATE__" "__TIME__"\n");
#endif
	//crcbios();
    printf(" LiteX git sha1: "LITEX_GIT_SHA1"\n");
    printf(" PogoSoC git sha1: "POGOSOC_GIT_SHA1"\n");
    pogobot_helper_print_version();
    if(unique_id != 0) printf(" Unique ID: 0x%08lx%08lx\n", (uint32_t)(unique_id>>32), (uint32_t)(unique_id & 0xffffffff));
    if(serial_number != 0) { printf(" Serial #: 0x%08lx%08lx, ", (uint32_t)(serial_number>>32), (uint32_t)(serial_number & 0xffffffff));
    printSerial(); }
    printf("\n");
#ifdef REMOCON
    printf(" Remote control for pogobots\n");
#else
    printf(" Battery voltage : %ld mV\n", (ADC_Read(3)*6445)/1000);
#endif
    printf("\n--=============== \e[1mSoC\e[0m ==================--\n");
	printf("\e[1mCPU\e[0m:\t\t%s @ %dMHz\n",
        CONFIG_CPU_HUMAN_NAME,
        CONFIG_CLOCK_FREQUENCY/1000000);
    printf("\e[1mBUS\e[0m:\t\t%s %d-bit @ %dGiB\n",
        CONFIG_BUS_STANDARD,
        CONFIG_BUS_DATA_WIDTH,
        (1 << (CONFIG_BUS_ADDRESS_WIDTH - 30)));
    printf("\e[1mCSR\e[0m:\t\t%d-bit data\n",
        CONFIG_CSR_DATA_WIDTH);
    printf("\e[1mROM\e[0m:\t\t%dKiB\n", ROM_SIZE/1024);
    printf("\e[1mSRAM\e[0m:\t\t%dKiB\n", SRAM_SIZE/1024);
#ifdef CONFIG_L2_SIZE
    printf("\e[1mL2\e[0m:\t\t%dKiB\n", CONFIG_L2_SIZE/1024);
#endif

#if !defined(TERM_MINI) && !defined(TERM_NO_HIST)
        hist_init();
#endif

    // color wheel memory
    uint8_t wheelpos = 0;

#ifndef REMOCON
    uint8_t i;
    static const char str_magic[] = IR_MAGIC_REQ;
    //standby timer
    time_reference_t my_standby_timer;
    uint8_t debug_mode = 0;     // debug_mode at 1 if uart connected

#ifdef RGB_LEDS
    rgb_blink_set_time(5, 995); // 5ms flash every second
    update_led_status();
#else
    rgb_set(255,0,0);
#endif
#else //REMOCON
    // Set power to max if remocon
    IRn_conf_tx_power_write( 0, 3 ); 
#ifdef RGB_LEDS
    rgb_set(0,10,10);
#endif
#endif

    printf("\n%s", POGOPROMPT);

    // main loop
    while(1) {

#ifndef REMOCON
        // standby control
        if (standby_status > 0)
        {
            if (standby_status == 2)
            {
                // wait 6 secondes deaf
                rgb_set(0, 0, 0);
                pogobot_timer_init( &my_standby_timer, 6000000 );
                while (!pogobot_timer_has_expired( &my_standby_timer )) 
                { 
                    //do nothing
                    __asm__( /* Assembly function body */
                    "  nop	\n"
                    "  nop	\n"
                    "  nop	\n"
                    "  nop	\n"
                    "  nop	\n"
                    "  nop	\n"
                    );
                }

                // ending hibernation
                standby_status = 1;
                standby_reloaded = 0;
                int i=0;
                for( i=0; i<IR_RX_COUNT; i++) {
                    ts_wakeUp(i);
                }

            } else if (standby_status == 1) {

                // listen during 3 seconds 
                if (!standby_reloaded)
                {
                    rgb_set(30, 30, 30);
                    msleep(5);
                    rgb_set(0, 0, 0);
                    pogobot_timer_init( &my_standby_timer, 3000000 );
                    standby_reloaded = 1;
                }
                if (pogobot_timer_has_expired( &my_standby_timer ))
                {
                    // go to hibernation
                    int i=0;
                    for( i=0; i<IR_RX_COUNT; i++) {
                        ts_goToSleep(i);
                    }
                    standby_status = 2;
                }

            }
            
        } else if (voltage_status == 1)
        {
            command_dispatcher("bat_life", 0, NULL);
            // no need to check the flash status

        } else if (autotest_status == 1)
        {
            if ( !autotest_done) {
                command_dispatcher("auto_test", 0, NULL);
                // no need to check the flash status
                autotest_done = 1;
            }

        } else {
            if( debug_mode == 0 ) rgb_blink(); // Blink when not debugging 
        }
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

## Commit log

2022-07-05 initial commit for Hardware / Tools and Readme
    [2199119-3.stp, ICM-20689.stl, ICM-20689.stp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]
2022-07-05 adding footprints and symbols
2022-07-05 adding usb uart program board
    [progboard.kicad_pcb, progboard.kicad_sch]
2022-07-08 initial Software commit
    [IR_mesure.ods, NNtiming.ods]
2022-09-22 improve SPI flashing documentation
2022-09-26 adding PCB v3 addons
    [pogobot_bellyv3_cap.stl, pogobot_bellyv3_skirt.stl, pogobot_bellyv3_skirt_brosse.stl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]
2022-09-26 adding pogobot charger
    [Pogocharge.kicad_pcb, Pogocharge.kicad_sch, pogocharger_cone.stl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]
2022-10-04 adding goto sleep for the IMU
2022-10-04 bugfix range color led voltage
    [cmd_pogobot.c]
2022-10-04 changing standby led intensity
2022-10-05 adding voltage mode
2022-10-05 adding voltage mode command
2022-10-05 Changing all IR messages over slip message
    [cmd_ir.c, main.c]
2022-10-10 adding little cercle on the charger
    [Pogocharge.kicad_pcb]
2022-10-10 changing the led behavior of standby
2022-10-11 first ir flashing version (no error mgt)
    [boot.c, cmd_ir.c, ir_boot.c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]
2022-10-12 correction of the SPI base flash
2022-10-12 Fixed path removed in kicad files, symlinks added
    [Pogobot-head.kicad_pcb, bellyv2.kicad_pcb]
2022-10-13 all fixed links replaced by
    [Package.step, TLA2024.step, TS4231.step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]
2022-10-18 adding remote screw info
2022-10-18 addinf remote 3D files
    [pogoremote_down.stl, pogoremote_up.stl]
2023-01-05 update 3d models
    [pogobot_bellyv2.1_skirt.stl, pogobot_bellyv2.1_skirt_brosse.stl, pogobot_bellyv3_cap.stl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]
2023-01-05 update 3d printing info on readme
2023-03-29 fixing bug for charger
    [Pogocharge.kicad_pcb]
2023-04-11 adds bidirectionnal motor command
2023-04-12 bug fix on spi_sr_register and test functions
    [cmd_pogobot.c, spi.c]
2023-06-13 modify IR timing to slow down transmission and improve stability
    [ts4231.py]
2023-06-13 adding remote and remote strip
    [PowerIRLED.kicad_sch, remote.kicad_pcb, remote.kicad_sch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]
2023-06-30 correcting sensor order
2023-06-30 adding memorisation of motor dir
2023-06-30 adding auto upload motor direction inside pogobot init
2023-06-30 adding bios command to memorize motor direction
2023-06-30 adding power motor management in comment
2023-07-03 bug fix get/set power motor + cleanup to gain space
    [cmd_ir.c, cmd_pogobot.c, pogobot.h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]
2023-07-04 adding set motor power mem
2023-08-28 correcting all send bios and usr message
    [cmd_ir.c]
2023-08-29 adding new hardware elements (pogo_object, active wall)
    [PowerIRLED.kicad_sch, pogo_object.kicad_pcb, pogo_object.kicad_sch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]
2023-08-29 bugfix: typo in function definition
    [pogobot.h]
2023-09-01 adding battery voltage monitoring
    [pogo_object.kicad_pcb, pogo_object.kicad_sch]
2023-09-04 adding battery control inside the webapp
2023-09-04 adding battery control, change object name and had a missing declaration
    [pogobject.ino]
2023-09-06 upgrade wall led strip from 20cm to 50cm
    [remote_leds_wall_strip.kicad_pcb, remote_leds_wall_strip.kicad_sch]
2023-09-12 changing the size of the strip led from 50 to 30cm
    [remote_leds_wall_strip.kicad_pcb, remote_leds_wall_strip.kicad_sch]
2023-09-26 adding short header message capability + example
    [main.c, pogobot.h]
2023-09-29 correcting missleading printf
2023-10-20 repairing not working ir programmation
    [cmd_ir.c]
2023-10-23 adding release.h and the print helper, update doc
2023-10-23 removing the auto reboot after programing a robot with serialboot
    [boot.c]
2023-11-07 correcting a too much buffer allocation
    [main.c]
2024-01-09 correcting cmd name in helper
    [cmd_pogobot.c]
2024-01-15 updates the pogobject pcb to include config mode
    [pogo_object.kicad_pcb, pogo_object.kicad_sch]
2024-01-18 fix bug on missing write to eeprom
    [pogobject.ino]
2024-01-26 changes the API and corrects names (API 2.3)
    [boot.c, cmd_pogobot.c, pogobot.h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]
2024-02-12 update resistance values
    [remote_leds_wall_ctrl.kicad_sch, remote_leds_wall_strip.kicad_sch]
2024-03-13 adjust timing to allow correct programmation
    [boot.c]
2025-01-13 adds 12v leds schematic
    [2199119-3.stp, ICM-20689.stl, ICM-20689.stp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]
2025-01-13 change transistor in wall crtl
    [remote_leds_wall_ctrl.kicad_pcb, remote_leds_wall_ctrl.kicad_sch]
2025-06-04 Add pogowall ctrl 3d models
    [pogowall_ctrl_down.stl, pogowall_ctrl_up_l.stl, pogowall_ctrl_up_r.stl]
2025-09-10 adding belly v3
    [motor_ctrl.kicad_sch]
2025-09-11 missing files for v3
    [10132797-015100LF.stp, 10132797-035100LF.stp, C_0603_1608Metric.step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]
2025-11-26 fix: typos in information prints
    [boot.c]
2026-05-12 Moved 3d-addons
    [pogobot_bellyv2.1_cap.stl, pogobot_bellyv2.1_skirt.stl, pogobot_bellyv2.1_skirt_brosse.stl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]
2026-05-12 Update 3d-addons to 2026 models
    [pogobot_bellyv2.1_cap.stl, pogobot_bellyv2.1_skirt.stl, pogobot_bellyv2.1_skirt_brosse.stl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]
2026-05-12 Add Pogobot2026 stl files
    [black_anulus.stl, black_capsule.stl, brushes.stl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]
2026-05-12 Replace old api doc with Doxygen
    [pogobot.h]
2026-05-12 Move charger doc back to Hardware

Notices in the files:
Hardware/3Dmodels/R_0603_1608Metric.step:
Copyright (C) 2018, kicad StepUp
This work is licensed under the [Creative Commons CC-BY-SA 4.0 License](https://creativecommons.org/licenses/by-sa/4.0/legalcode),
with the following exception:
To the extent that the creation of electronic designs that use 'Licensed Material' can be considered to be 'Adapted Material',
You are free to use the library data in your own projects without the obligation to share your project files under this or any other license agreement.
